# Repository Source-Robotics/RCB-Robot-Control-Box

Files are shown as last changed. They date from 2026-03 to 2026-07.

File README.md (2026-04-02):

> [!CAUTION]
> This is a BETA release: Instructions, code, and 3D print files may change in the future and are not yet finalized.

By building and using this system, you acknowledge that it is still under active development and may contain errors, incomplete features, or design issues. You are doing so entirely at your own risk and responsibility.

This project may require troubleshooting, modifications, and technical knowledge. Proceed only if you are comfortable working with electronics, mechanical systems, and software in a development-stage environment.
>

## 🐞 Beta Feedback

Since this project is currently in beta, feedback is highly appreciated.

If you find any mistakes, bugs, or unclear parts, please report them, including issues in:

- Documentation
- BOM and assembly documentation
- Source code
- STL and other 3D print files

Please open an issue, send us a message on Discord, or contact us via email with as much detail as possible so we can fix it quickly.



<div align="center">

# RCB - ROBOT CONTROL BOX


     
<p align="center">
  
  
  
  
  
  
</p>

</div>

## 📖 Project Overview

RCB - Robot Control Box  is basically the brain + interface hub of the PAR6 robot, it:

* Runs the real-time control algorithms
* Connects to the robot arm (motors, sensors)
* Interfaces with external devices (PCs, PLCs, sensors)
* Handles safety systems
* Provides user interface / programming environment

There is no need for external PC, the Box uses raspberry pi to control your robotic arm.

## ⚒️How to build / Where to buy?

* Assembly manual is TODO.

* Source all the parts yourself from the BOM folder!

* Print files from the STEP files folder.

## 📚Resources:

| Resource | Description |
|---|---|
| [RCB motherboard firmware](RCB%20motherboard%20firmware/) | Firmware source and PlatformIO project for the control box motherboard |
| [BOX STEP 3D print files](STEP%20files/) | STEP files for the control box enclosure and printed parts |
| [BOM](BOM/BOM.md) | Bill of materials and reference images for required components |
| [Assembly manual](Assembly%20manual/readme.md) | Build and assembly instructions for the control box TODO |

## 🌐 More about our projects

| YouTube | Instagram | Twitter | LinkedIn |
|---|---|---|---|
|  |  |  |  |

| Discord | Forum | Hackaday | Blog |
|---|---|---| ---|
|  |  |  |  

## ⚠️ Safety, Liability & Disclaimer
This project includes experimental software, hardware designs, and assembly documentation that are still under development and may contain bugs, errors, or incomplete features. By using, building, or modifying this project, you acknowledge that:

* You use this project entirely at your own risk
* You are solely responsible for safe assembly, testing, and operation
* No guarantee is made regarding correctness, safety, or reliability
* The authors are not responsible for any damage, injury, or loss resulting from the use or misuse of this project
* Hardware performance and safety depend on user assembly, component quality, calibration, and handling, which cannot be guaranteed
* This project is provided “as is.” If you choose to build a device yourself using these files, designs, or instructions, you do so without any warranties or guarantees, including regarding safety, reliability, or suitability for any particular purpose.

THIS PROJECT INVOLVES LETHAL VOLTAGES AND OTHER SERIOUS HAZARDS THAT CAN CAUSE SEVERE INJURY. YOU MUST READ THE FULL [SAFETY WARNING AND DISCLAIMER DOCUMENT](SAFETY_WARNING_AND_DISCLAIMER.md)  BEFORE USING ANY PROJECT FILES. BY PROCEEDING, YOU ACKNOWLEDGE AND ACCEPT ALL RISKS AND AGREE TO USE THIS PROJECT ENTIRELY AT YOUR OWN RESPONSIBILITY.

## 💸Support us

The majority of this project is open source and freely available to everyone. Your assistance, whether through donations or advice, is highly valued. Thank you!

 


## 🛡️ Licensing
 Project is under the [MIT License](LICENSE).

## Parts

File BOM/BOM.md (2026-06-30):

# RCB Robot Control Box – Bill of Materials (BOM)

This BOM lists all components required to build RCB Robot Control Box. Quantities are for **one RCB**.

> [!NOTE]
> If any product links are broken, unavailable, or no longer point to the correct item, please [open an issue](https://github.com/Source-Robotics/RCB-Robot-Control-Box/issues/new), send us a message on Discord, or contact us via email. You can also use the reference images to find the same or an equivalent part from another supplier.

---

## Screws and Nuts

| Diameter / Type | Length | Quantity | Description |
|---|---|---|---|
| M2.5 nut |  | 4 |  |  |
| M3  |  8mm| 12 | DIN 912 / ISO 4762 (Socket head cap) |  
| M3  | 20mm | 2 | DIN 912 / ISO 4762 (Socket head cap) |  
| M3  | 30mm | 1 |  DIN 912 / ISO 4762 (Socket head cap)|  
| M3 tappered head  | 6mm | 11 | Tapered / Countersunk screw head |  
| M2 | 6mm | 2 |  DIN 912 / ISO 4762 (Socket head cap) | 
| M2.5 | 18mm | 4 | Any type |  

---

## Brass Inserts

| Thread | Length | Outer Diameter | Quantity | Link | Reference Image |
|---|---|---|---|---| ---|
| M3 | 5 mm | 4.5 mm | 13 | [Link](https://s.click.aliexpress.com/e/_c2RX6lzp)  |[Link](BOM%20reference%20images/brass_insert.png) |

---

## Mechanical Components

| Type | Quantity | Description | Link | Reference Image |
|---|---|---|---| ---|
| Rubber feet | 4 | See reference image for exact type | [Link](https://s.click.aliexpress.com/e/_c2xnQgI7)  |[Link](BOM%20reference%20images/Rubber_feet.png) |

---
female_female_jumper_wire
## Electronics

| Type | Quantity | Description | Link | Reference Image |
|---|---|---|---| ---|
| RCB Motherboard | 1 |  | Source Robotics website only for beta for now | [Link](BOM%20reference%20images/Motherboard.png) |
| Raspberry pi - Motherboard connector PCB | 1 | Connects pi5 to motherboard | Source Robotics website only for beta for now  | [Link](BOM%20reference%20images/P1066620.jpg) |
| UHP-200-24 MEAN WELL power supply | 1 |  | [Link](https://hr.mouser.com/ProductDetail/709-UHP-200-24) | [Link](BOM%20reference%20images/psu.png) |
| I2C Oled display 128x64 0.96 inch | 1 |  | [Link](https://s.click.aliexpress.com/e/_c3Gz8Xj7) | [Link](BOM%20reference%20images/OLED.png) |
| Power socket | 1 |  | [Link](https://s.click.aliexpress.com/e/_c3jE9sYt) | [Link](BOM%20reference%20images/Power_plug.png) |
| ON/OFF Button | 1 | 12mm 3-6V, NOT LATCHING  | [Link](https://s.click.aliexpress.com/e/_DBpZV3h) | [Link](BOM%20reference%20images/button.png) |
| 3mm LED diode (green recommended) | 2 | Indicator LEDs | [Link](https://s.click.aliexpress.com/e/_c39Q5Qz7) |  [Link](BOM%20reference%20images/green_lred_3mm.webp) |
| 12 AWG wire | 1meter | Wire used for Power socket and Power supply - motherboard connection | Local store | [Link](BOM%20reference%20images/instalation_wire.jpg) |
| 2.54 Female - Female wire 10cm | 4 | Wires used for OLED display | [Link](https://s.click.aliexpress.com/e/_c2xKgSEl) | [Link](BOM%20reference%20images/female_female_jumper_wire.jpg) |
| JST PH 2.0mm 200mm 4PIN | 1 | Cable used for power button | [Link](https://s.click.aliexpress.com/e/_DeObQ1D) | [Link](BOM%20reference%20images/wire.png) |
| Raspberry pi 5 4gb or higher | 1 |  |  | [Link](BOM%20reference%20images/pi5.png) |
| GX16 4PIN connector male | 1 |  | [Link](https://s.click.aliexpress.com/e/_c3o4afqR) | [Link](BOM%20reference%20images/GX16.jpg) |
| SV 1.25-4S Spades/Fork Connector | 7 | Used for Power socket and MEANWELL power supply | [Link](https://s.click.aliexpress.com/e/_c31y7RJF) | [Link](BOM%20reference%20images/Fork_spade_plug.png)  |
| MICRO-FIT 3.0 2Pin | 1 | Cable from GX16 to motherboard  | [Link](https://hr.mouser.com/ProductDetail/Molex/214755-1021?qs=vmHwEFxEFR9098107Evnhw%3D%3D) [Aliexpress link](https://s.click.aliexpress.com/e/_c3MQyASH) | [Link](BOM%20reference%20images/Micro_fit_3_0_2pin.png) |
| JST ZH 1.5MM 2PIN female-female 23cm | 1 | Cable from GX16 to motherboard  | [Link](https://s.click.aliexpress.com/e/_c39pDT7b) | [Link](BOM%20reference%20images/ZH_series_dual_female_head.jpg) |

### Raspberry Pi Cooling Options

Choose **one** cooling option: either use the 4010 cooling fan with heatsinks, or use the pi5 cooling fan kit.

| Option | Type | Quantity | Description | Link | Reference Image |
|---|---|---|---|---| ---|
| A | 4010 - Cooling fan 40x40x10, 5V | 1 | Use together with the heatsinks below. | [Link](https://s.click.aliexpress.com/e/_c3anlQut) | [Link](BOM%20reference%20images/cooling_fan_4010.png) |
| A | Heatsinks | 1 set | Use together with the 4010 cooling fan above. | [Link](https://s.click.aliexpress.com/e/_c4BNGgDT) | [Link](BOM%20reference%20images/heatsink.png) |
| B | pi5 cooling fan kit | 1 | Use this instead of the 4010 cooling fan and heatsinks. | [Link](https://s.click.aliexpress.com/e/_c3OpTQ3J) [alt link](https://s.click.aliexpress.com/e/_c3oBDnrF) | [Link](BOM%20reference%20images/pi5_cooling_kit.png) |

### Optional Cables

| Type | Quantity | Description | Link | Reference Image |
|---|---|---|---| ---|
| MICRO-FIT 3.0 2PIN connector or cable | 1 | Optional spare or alternate cable/connector. | [Link](https://s.click.aliexpress.com/e/_c3MQyASH) | [Link](BOM%20reference%20images/microfit2.png) |
| MICRO-FIT 3.0 8PIN connector or cable | 1 | Optional spare or alternate cable/connector. | [Link](https://s.click.aliexpress.com/e/_c3G9mlNf) | [Link](BOM%20reference%20images/microfit8.png) |

---

## PAR6 Robot cable (Robot base to RCB (Robot Control Box) cable)

* Follow the assembly manual [here](../Assembly%20manual/Building_cables.md)
* Video manual [here](https://youtu.be/QlNfWAga1l0)

| Type | Quantity | Description | Link | Reference Image |
|---|---|---|---| ---|
| GX16 4PIN connector female | 2 |  | [Link](https://s.click.aliexpress.com/e/_c3o4afqR) | [Link](BOM%20reference%20images/GX16.jpg) |
| Twisted Pair Shielded Cable 4 cores - 24AWG or 22AWG | 2m recommended |  | [Link](https://s.click.aliexpress.com/e/_c34NcZIT) | [Link](BOM%20reference%20images/TWISTED.png) |

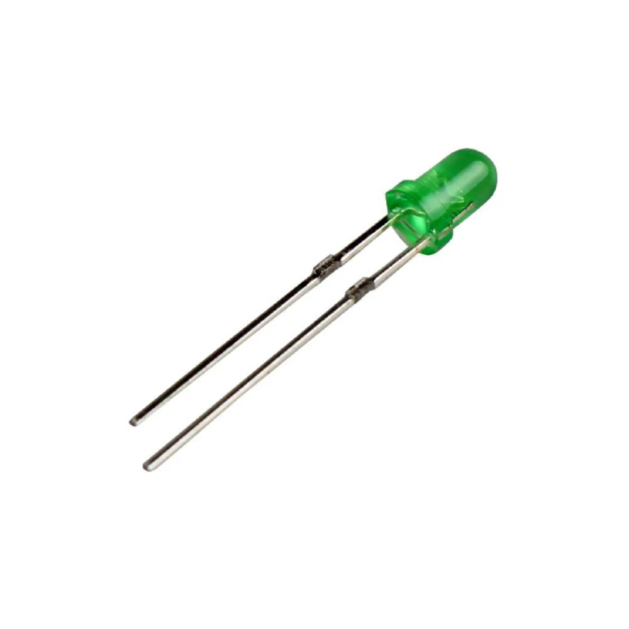
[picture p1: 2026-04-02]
BOM/BOM reference images/green_lred_3mm.webp

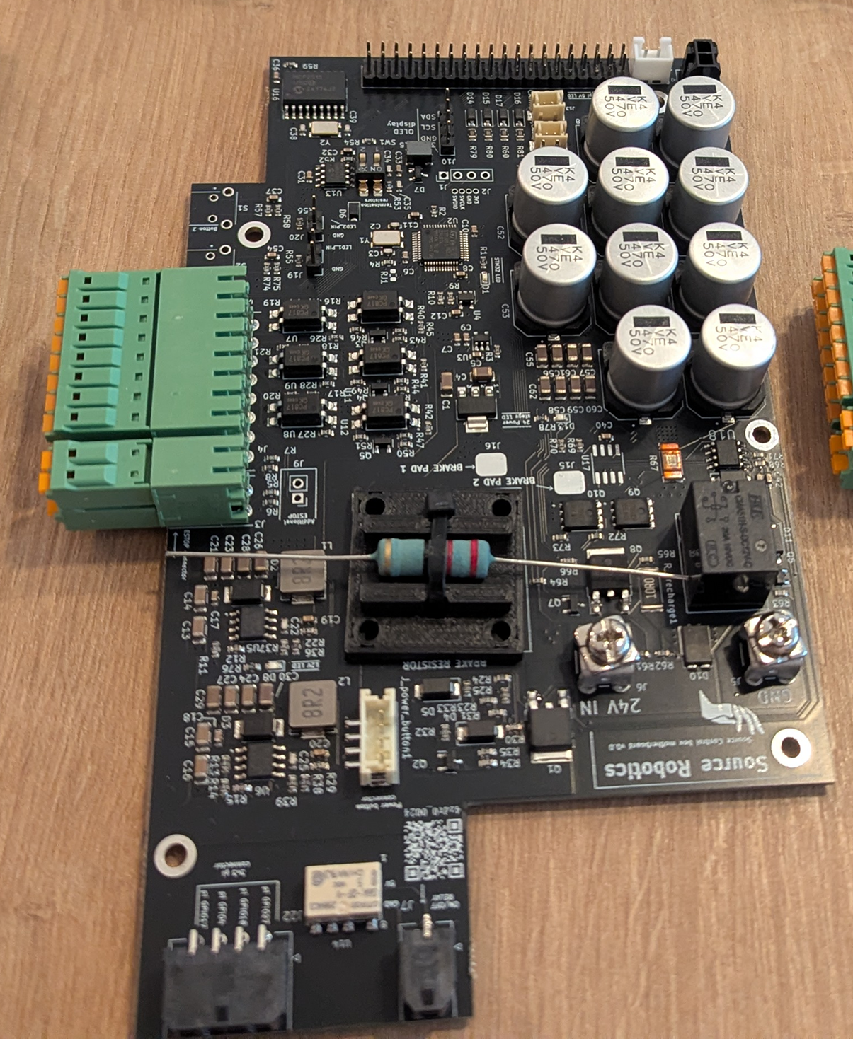
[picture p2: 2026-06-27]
BOM/BOM reference images/Motherboard.png

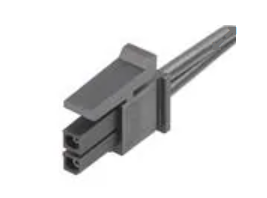
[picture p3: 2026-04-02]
BOM/BOM reference images/Micro_fit_3_0_2pin.png

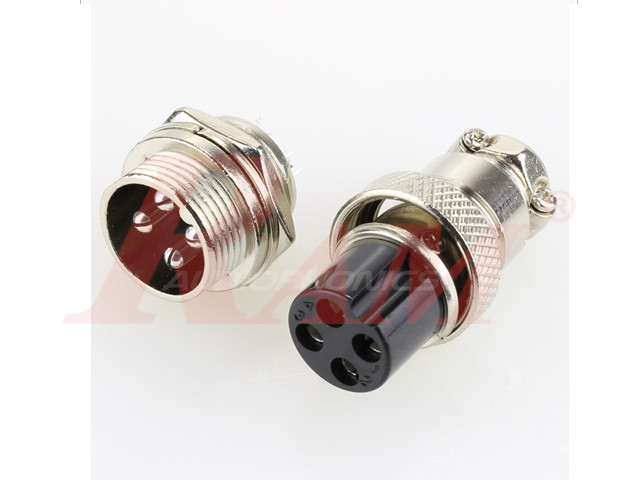
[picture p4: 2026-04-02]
BOM/BOM reference images/GX16.jpg

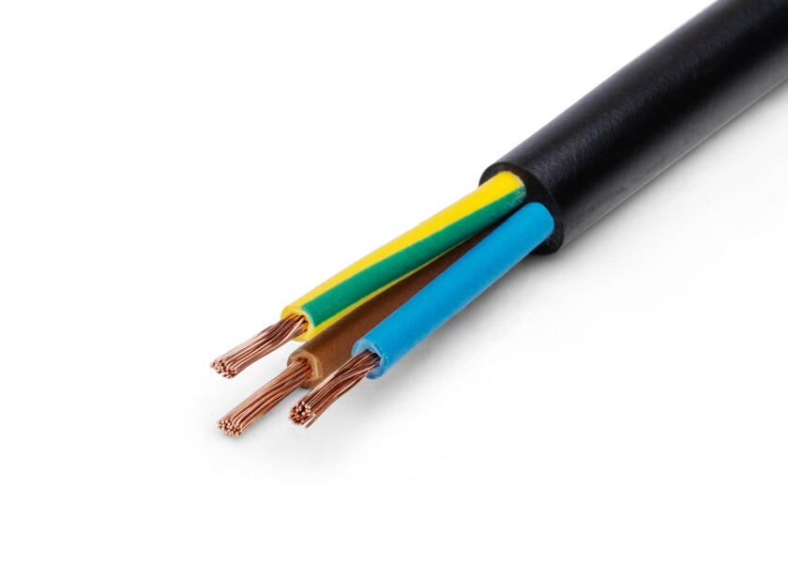
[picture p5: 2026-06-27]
BOM/BOM reference images/instalation_wire.jpg

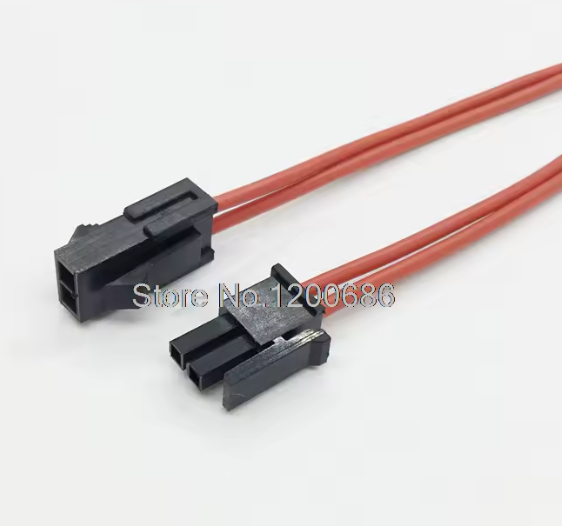
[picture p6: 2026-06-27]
BOM/BOM reference images/microfit2.png

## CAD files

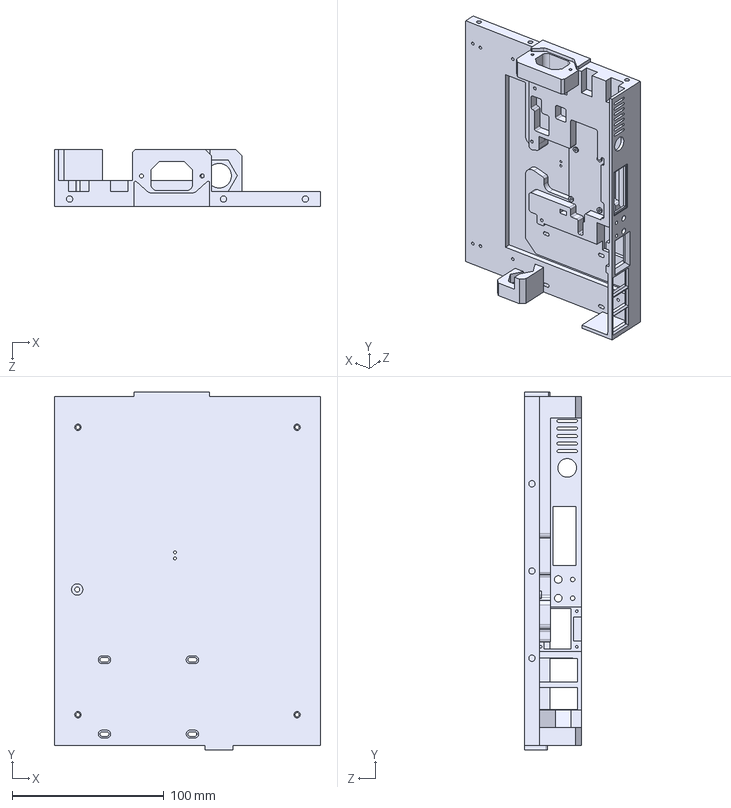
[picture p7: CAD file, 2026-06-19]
STEP files/Control_box_bottom.STEP
175.5 x 236.1 x 37.8 mm

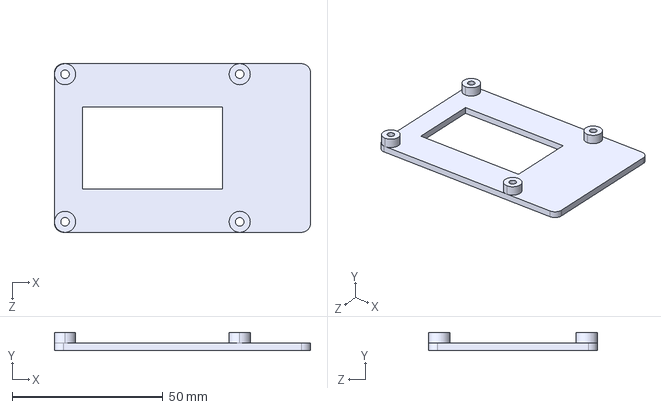
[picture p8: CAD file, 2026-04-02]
STEP files/pi_bottom.STEP
85.0 x 6.10 x 56.0 mm

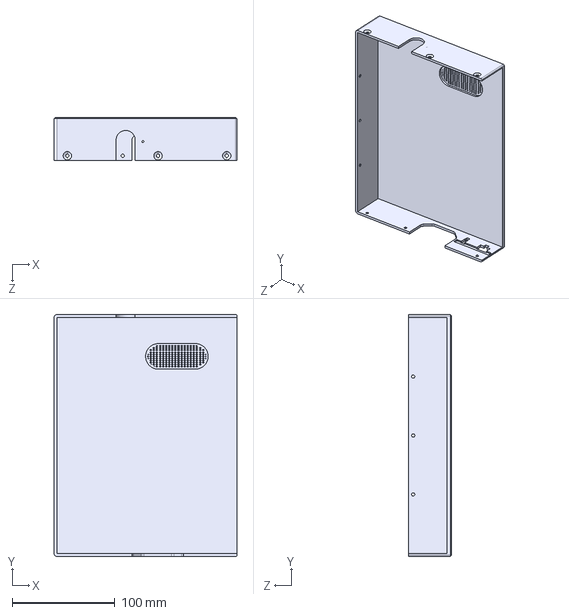
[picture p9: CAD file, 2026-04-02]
STEP files/Control_box_lid_no pattern.STEP
178.5 x 236.1 x 41.8 mm

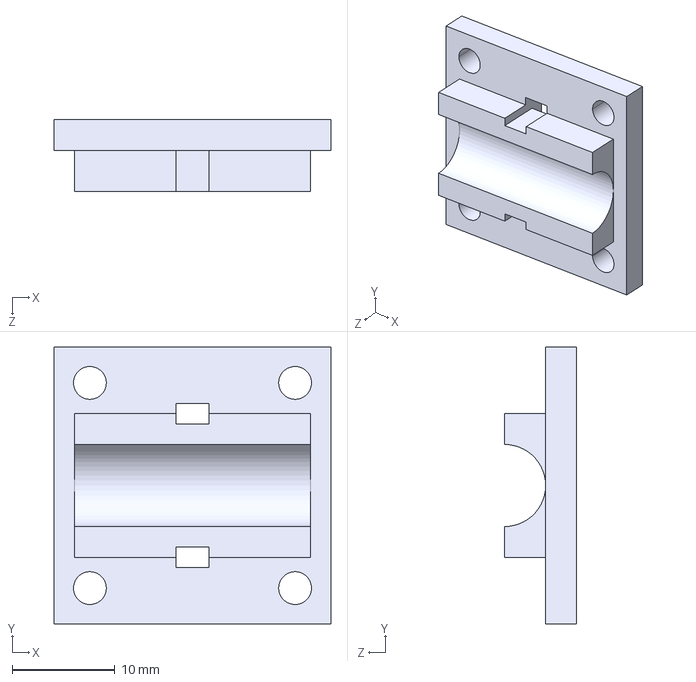
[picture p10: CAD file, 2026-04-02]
STEP files/resistor_holder.STEP
27.0 x 27.0 x 7.00 mm

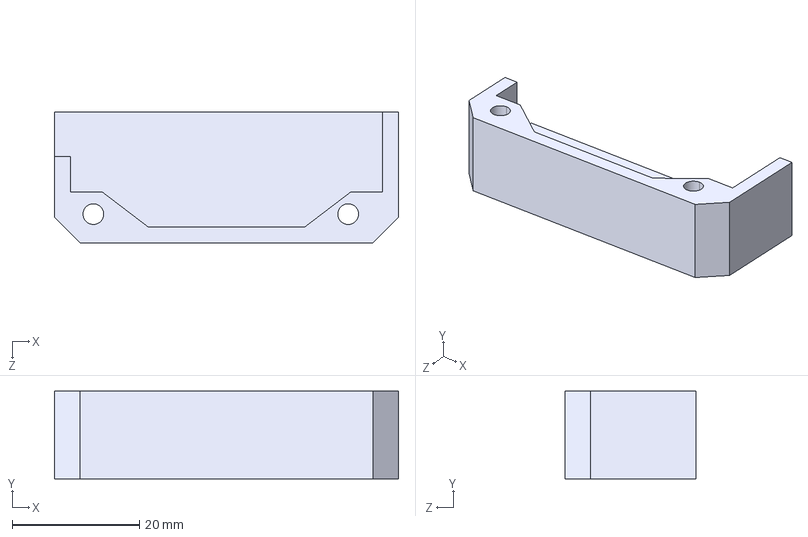
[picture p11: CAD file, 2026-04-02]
STEP files/Socket_cover.STEP
54.0 x 13.8 x 20.6 mm

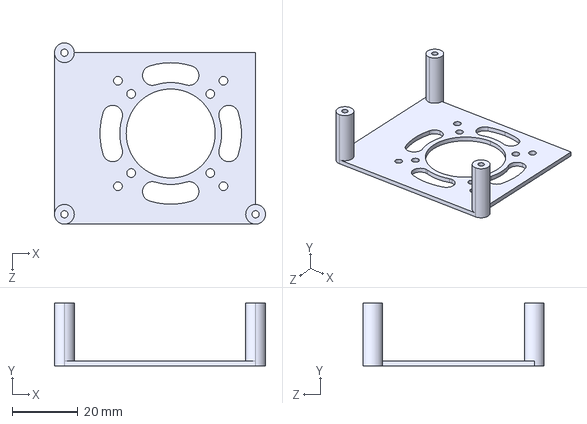
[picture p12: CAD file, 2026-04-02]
STEP files/pi_fan_holder.STEP
64.0 x 19.0 x 55.0 mm

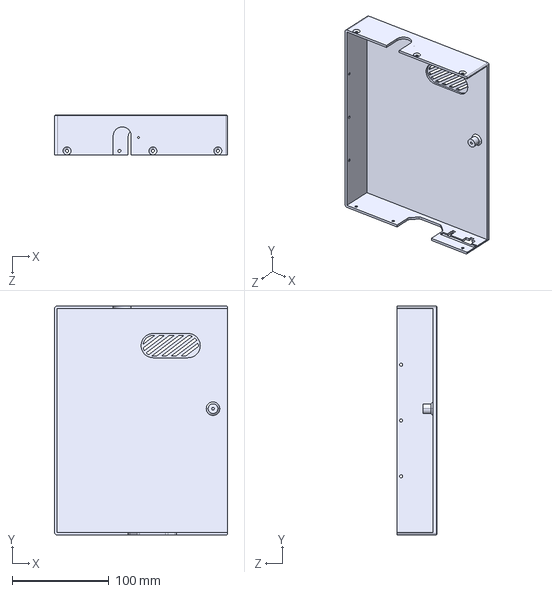
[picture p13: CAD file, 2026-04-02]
STEP files/Control_box_top_ribbed.STEP
178.5 x 236.1 x 41.8 mm

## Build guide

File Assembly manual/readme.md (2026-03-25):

Check youtube video assembly manual: Link

PDF TODO

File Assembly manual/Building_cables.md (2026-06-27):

## PAR6 Robot cable (Robot base to RCB (Robot Control Box) cable)

Parts needed:
* [2 x GX16 4PIN connector female](https://s.click.aliexpress.com/e/_c3o4afqR)
* [Twisted Pair Shielded Cable 4 cores - 24AWG or 22AWG](https://s.click.aliexpress.com/e/_c34NcZIT)

Check the video tutorial [here](https://youtu.be/QlNfWAga1l0)

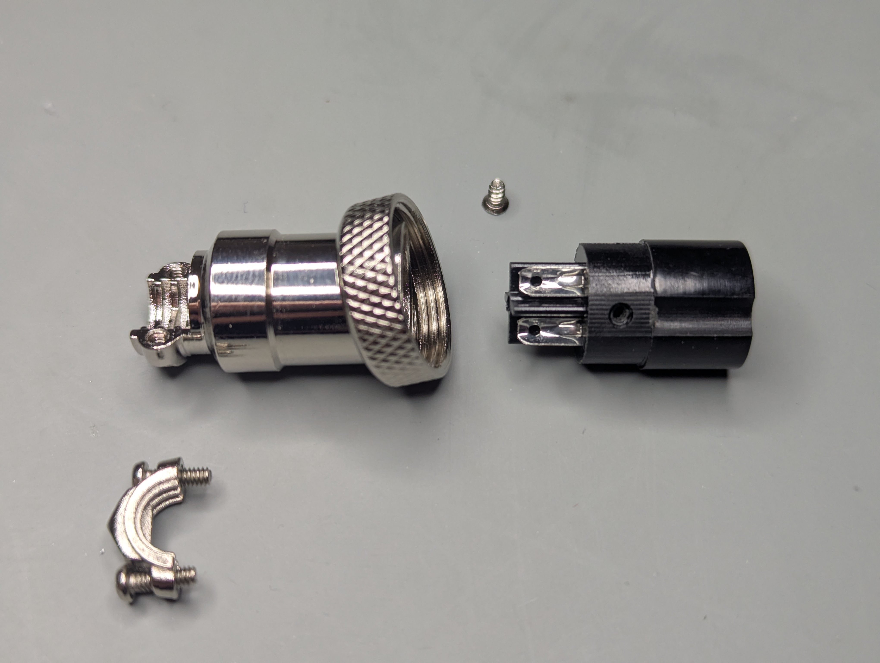
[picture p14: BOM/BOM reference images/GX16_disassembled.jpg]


**Dissasemble the connector.**

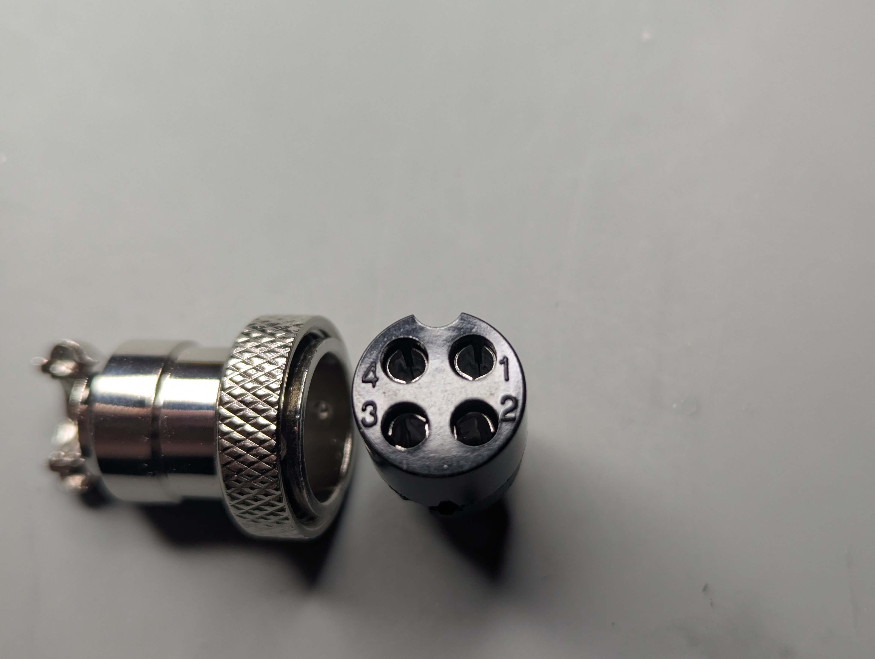
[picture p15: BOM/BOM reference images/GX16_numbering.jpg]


**Connector has numbering on both sides.** 

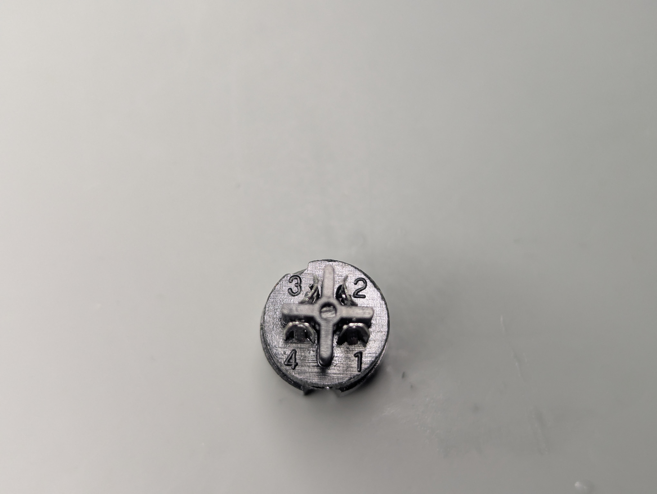
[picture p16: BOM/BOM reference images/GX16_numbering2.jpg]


**When assembling the cable you solder pins 1-1, 2-2, 3-3, 4-4. Do that for the both sides of the cable!** 

> **Note:** Equivalent parts from other suppliers may be used as long as specifications match.

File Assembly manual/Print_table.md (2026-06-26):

## USE 25% Infill for all! We used PETG filament!

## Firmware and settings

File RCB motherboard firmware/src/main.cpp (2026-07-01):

#include "stm32f1xx_hal.h"
#include "iodefs.h"
#include "constants.h"
#include "adc_init.h"
#include "pwm_init.h"
#include "hw_init.h"
#include "qfplib-m3.h"
#include "utils.h"
#include "EEPROM.h"
#include "debounce.h"
#include "SerialPacketParser.h"
#include "communication.h"
#include "common.h"

// Define serial port
#define Serial Serialx
#define TIMING_DEBUG 1
HardwareSerial Serialx(RX_COM, TX_COM); // PA3, PA2 RX,TX

// Define timer for PWM
HardwareTimer *MyTim2;
ADC_HandleTypeDef hadc1;

// Define button debounce and press handler
ButtonHandler button(Button_state);

// Exponential Moving Average (EMA) filter coefficients
#define EMA_A_V1 0.15
#define EMA_A_V2 0.15
#define EMA_A_C 0.15

String command_ = "idle";
String status = "test";

// Button function
void handleButtonActions() {
  switch (button.getState()) {
    case PRESSED:
        Serial.println("Single Press detected");
        break;
    case DOUBLE_PRESS:
        Serial.println("Double Press detected");
        break;
    case TRIPLE_PRESS:
        Serial.println("Triple Press detected");
        break;
    case HELD_2S:
        Serial.println("Button Held for 2 seconds");
        break;
    case HELD_3S:
        Serial.println("Button Held for 3 seconds");
        break;
    default:
        break;
}
button.resetState(); // Reset state after handling
}



void setup () {

  // Init system
  HAL_Init();
  SystemClock_Config();
  TM_SystemClock_Config(CLOCK_PRESCALE); //15, Clock speed = 8*15

  // Init digital inputs and outputs
  Init_Digital_Inputs();
  Init_Digital_Outputs();
  GPIO_init();

  // Init ADC
  MX_ADC1_Init();
  HAL_ADCEx_Calibration_Start(&hadc1);

  // Begin serial
  Serial.begin(SERIAL_SPEED);

  // Begin PWM 50000 = 25Khz -> center aligned
  // PWM duty for 25khz goes from 0 - 5120 if CPU clock is 128 Mhz
  MyTim2 = pwm_high(PRECHARGE_PIN, PWM_FREQ * 2);
  MyTim2 = pwm_high(PWM_BRAKE, PWM_FREQ * 2);
  pwm_align(MyTim2);

  // EEPROM stuff
  digitalWriteFast(EEPROM_WP, LOW);
  Init_EEPROM();
  //Write_config();
  Set_Default_config();
  read_config();

  // Init timer ticker with callback function
  Ticker_init(TIM3, LOOP_FREQ, IT_callback);

  // Disable relay and precharge FET on startup instantly
  digitalWriteFast(RELAY_PIN, HIGH); // relay is OFF
  pwm_set(PRECHARGE_PIN, PWM_MIN, 13); // 0V, Precharge FET is off, current goes thru relay

  // Enable brake FET to discharge capacitors that got slightly charged because of the relay is in NC state on startup
  digitalWriteFast(EN_BRAKE_FET, HIGH); // // Set PC15 HIGH, Enable brake FET   //HAL_GPIO_WritePin(GPIOA, GPIO_PIN_8, GPIO_PIN_SET);  
  pwm_set(PWM_BRAKE, PWM_MAX-10, 13); // 3V3, BRAKE FET  PWM

  // Small delay
  delay(500);

  // DISABLE brake FET
  digitalWriteFast(EN_BRAKE_FET, LOW); // Set PC15 LOW, Disable brake FET  //HAL_GPIO_WritePin(GPIOA, GPIO_PIN_8, GPIO_PIN_RESET);  
  pwm_set(PWM_BRAKE, PWM_MIN + 10, 13); // 0V, BRAKE FET is OFF

  // Enable precharge FET and wait a bit for CAPS to charge
  digitalWriteFast(RELAY_PIN, HIGH); // relay is OFF
  pwm_set(PRECHARGE_PIN, PWM_MAX, 13); // 3V3, Precharge FET is on
  delay(300);

  // Disable precharge FET and turn on relay 
  pwm_set(PRECHARGE_PIN, PWM_MIN, 13); // 0V, Precharge FET is off
  digitalWriteFast(RELAY_PIN, LOW); // relay is ON

  


}

void loop () {

  #if (TIMING_DEBUG > 0)
  int c = micros();
  #endif

  // Global ticker for timing
  uint32_t ms = HAL_GetTick();
  static uint32_t last_time = 0;

  // Turn on raspberry pi
  digitalWriteFast(Pi_enable, HIGH); 


  int vbus1 = Get_voltage_mA(ADC_CHANNEL_5_READ_VBUS1());
  int vbus2 = Get_voltage_mA(ADC_CHANNEL_4_READ_VBUS2());
  int current = Get_current_mA(ADC_CHANNEL_3_READ_CURRENT());


  // Apply integer-based EMA filtering

  controller.filtered_VBUS1_mV = (int)qfp_fadd(qfp_fmul(EMA_A_V1, vbus1), qfp_fmul(qfp_fsub(1, EMA_A_V1), controller.filtered_VBUS1_mV));
  controller.filtered_VBUS2_mV = (int)qfp_fadd(qfp_fmul(EMA_A_V2, vbus2), qfp_fmul(qfp_fsub(1, EMA_A_V2), controller.filtered_VBUS2_mV));
  controller.filtered_Current_mA = (int)qfp_fadd(qfp_fmul(EMA_A_C, current), qfp_fmul(qfp_fsub(1, EMA_A_C), controller.filtered_Current_mA));

  // Brake FET logic
  if (controller.filtered_VBUS2_mV >25000){
    digitalWriteFast(EN_BRAKE_FET, HIGH); // // Set PC15 HIGH, Enable brake FET   //HAL_GPIO_WritePin(GPIOA, GPIO_PIN_8, GPIO_PIN_SET);  
    controller.brake_pwm_duty = 8100;
    pwm_set(PWM_BRAKE, controller.brake_pwm_duty, 13); // 3V3, BRAKE FET  PWM
    digitalWriteFast(LED1, HIGH);
  }

  if(controller.filtered_VBUS2_mV < 25000){
    digitalWriteFast(EN_BRAKE_FET, LOW); // // Set PC15 HIGH, Enable brake FET   //HAL_GPIO_WritePin(GPIOA, GPIO_PIN_8, GPIO_PIN_SET);  
    controller.brake_pwm_duty = 8;
    pwm_set(PWM_BRAKE, controller.brake_pwm_duty , 13); // 3V3, BRAKE FET  PWM
    digitalWriteFast(LED1, LOW);
  }
  ////////////////////////

  if ((ms - last_time) > 500) // run every x ms
  {

    /*
    int vbus1 = ADC_CHANNEL_5_READ_VBUS1();
    int vbus2 = ADC_CHANNEL_4_READ_VBUS2();
    int current = ADC_CHANNEL_3_READ_CURRENT();
    Serial.print("VBUS1: ");
    int vvbus1 = Get_voltage_mA(vbus1);
    int vvbus2 = Get_voltage_mA(vbus2);
    Serial.print(vvbus1);
    Serial.print(" VBUS2: ");
    Serial.print(vvbus2);
    Serial.print(" Current: ");
    Serial.println(Get_current_mA(current));
    Serial.print("exect time: ");
    Serial.println(controller.execution_time);
    */


    // Print filtered integer values


    // TODO Add error state 
    // TODO add power button state
    // Read relay state: 
    int relayState = !digitalRead(RELAY_PIN);
    
    float power_usage = (((controller.filtered_VBUS1_mV + controller.filtered_VBUS2_mV) / 2) * controller.filtered_Current_mA)/1000000;
    Serial.print("$");
    Serial.print(" ");
    Serial.print(controller.filtered_VBUS1_mV);
    Serial.print(" ");
    Serial.print(controller.filtered_VBUS2_mV);
    Serial.print(" ");
    Serial.print(controller.filtered_Current_mA);
    Serial.print(" ");
    Serial.print(power_usage);
    Serial.print(" ");
    Serial.print(relayState);
    Serial.print(" ");
    Serial.print(command_);
    Serial.print(" ");
    Serial.print(status);
    Serial.print(" ");
    Serial.print(controller.SERIAL_NUMBER);
    Serial.print(" ");
    Serial.print(controller.HARDWARE_VERSION);
    Serial.print(" ");
    Serial.print(controller.BATCH_DATE);
    Serial.print(" ");
    Serial.print(controller.SOFTWARE_VERSION);
    Serial.println(" ");

    /*
    Serial.print(controller.filtered_VBUS1_mV );         // first variable is program time in seconds. This can be plotted on an x-axis!
    Serial.print("\t");
    Serial.print(controller.filtered_VBUS2_mV);   // second variable is sin(t)
    Serial.print("\t");      // this last "\t" isn't required, but doesn't hurt
    Serial.println(vbus1); // third varible is cos(t). make sure to finish with a println
    */




    /*
    Serial.print("Terst ");
    Serial.print(Get_voltage_mA(1500));
    Serial.print("Filtered VBUS1: ");
    Serial.print(controller.filtered_VBUS1_mV);
    Serial.print("  Filtered VBUS2: ");
    Serial.print(controller.filtered_VBUS2_mV);
    Serial.print("  Filtered Current: ");
    Serial.println(controller.filtered_Current_mA);
    Serial.print("Exec time: ");
    Serial.println(controller.execution_time);
    */


  last_time = ms;
  }



  /*
  Check for VBUS error
  */
  check_vbus_error(ms);

  /*
  Perform actions based on button state (also debounce it)
  */
  button.update();
  handleButtonActions();

  /*
  UART CLI INTERFACE
  */
  UART_protocol(Serial);
  Cyclic_UART(Serial, ms);

  /*
  Debug variables
  */
  #if (TIMING_DEBUG > 0)
  int c2 = micros();
  controller.execution_time = c2 - c;
  #endif
}

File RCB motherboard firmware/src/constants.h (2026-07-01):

/* USER CODE BEGIN Header */
/**
 ******************************************************************************
 * @file    constants.h
 * @brief   This file provides code where we declare constants
 * @author Petar Crnjak
 ******************************************************************************
 * @attention
 *
 * Copyright (c) Source robotics.
 * All rights reserved.
 *
 * This software is licensed under terms that can be found in the LICENSE file
 * in the root directory of this software component.
 * If no LICENSE file comes with this software, it is provided AS-IS.
 *
 ******************************************************************************
 */

/* Define to prevent recursive inclusion -------------------------------------*/
#ifndef CONSTANTS_H
#define CONSTANTS_H

#define VBUS_ERROR_TIME 4000 // Time in ms for VBUS error detection
#define MAX_DUTY 0.95f

#define MIN_DUTY 0.05f

#define ADC_RESOLUTION_ 12

#define PI 3.14159265359f

#define PI2 6.283185307f

#define PWM_FREQ 25000

#define LOOP_FREQ 5000 

#define LOOP_TIME 0.0002 

#define CLOCK_PRESCALE 14

#define SERIAL_SPEED 256000 // 256000 works, Tested with 1Mbit and works

#define SENSE_RESISTOR 0.0005f

#define ADC_MIDPOINT 1.65f

#define ADC_MIDPOINT_BIT 2048

#define CURRENT_AMP_GAIN 200

#define R1_1 180000

#define R2_1 10000

#define R1_2 180000

#define R2_2 10000

#define PWM_MAX 8191

#define PWM_MIN 0

/*
EEPROM CONSTANTS
*/

///// EEPROM variable address list
#define SERIAL_NUMBER_EEPROM 32
#define HARDWARE_VERSION_EEPROM 36
#define BATCH_DATA_EEPROM 40
#define SOFTWARE_VERSION_EEPROM 48

#endif

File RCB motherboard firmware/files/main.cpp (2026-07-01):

#include "hw_init.h"
#include "pwm_init.h"
#include "utils.h"
#include "stm32f1xx_hal.h"
#include "adc_init.h"
#include "iodefs.h"
#include "qfplib-m3.h"
#include "SerialPacketParser.h"
#include "constants.h"
#include "motor_control.h"
#include <SPI.h>
#include "common.h"
#include "foc.h"
#include "temperature_table.h"
#include "CAN.h"
#include <Wire.h>
#include <I2C_eeprom.h>
#include "communication.h"
#include "EEPROM.h"
#include "communication_CAN.h"





// Define serial port
#define Serial Serialx
HardwareSerial Serialx(RX_COM, TX_COM); // PA3, PA2 RX,TX

// Define timer for PWM
HardwareTimer *MyTim2;
ADC_HandleTypeDef hadc1;

void setup()
{

  SPI.setMOSI(MOSI);
  SPI.setMISO(MISO);
  SPI.setSCLK(CLK);
  SPI.setClockDivider(SPI_CLOCK_DIV8); // High speed (128 / 8 = 16 MHz SPI_1 speed)

  Init_Digital_Inputs();
  Init_Digital_Outputs();

  // Sleep mode input.Logic high to enable device;
  // logic low to enter low-power sleep mode; internal pulldown
  digitalWriteFast(SLEEP, HIGH);
  // Reset input. Active-low reset input initializes internal logic, clears faults,
  // and disables the outputs, internal pulldown
  digitalWriteFast(RESET, HIGH);

  digitalWriteFast(EN1, HIGH);
  digitalWriteFast(EN2, HIGH);
  digitalWriteFast(EN3, HIGH);
  digitalWriteFast(LED, HIGH);

  // Init system
  HAL_Init();
  SystemClock_Config();
  TM_SystemClock_Config(14); //15, Clock speed = 8*15

  // Init ADC
  MX_ADC1_Init();
  HAL_ADCEx_Calibration_Start(&hadc1);

  // Begin serial
  Serial.begin(SERIAL_SPEED);

  delay(50);

  digitalWrite(EEPROM_WP, LOW);
  Init_EEPROM();
  //Write_config();
  read_config();
  delay(100);

  // Begin PWM 50000 = 25Khz -> center aligned
  // PWM duty for 25khz goes from 0 - 5120 if CPU clock is 128 Mhz
  MyTim2 = pwm_high(PWM_CH1, PWM_FREQ * 2);
  MyTim2 = pwm_high(PWM_CH2, PWM_FREQ * 2);
  MyTim2 = pwm_high(PWM_CH3, PWM_FREQ * 2);
  pwm_align(MyTim2);

  // Get initial encoder value!
  Get_first_encoder();

  // Collect data before entering the ISR
  // This fixes velocity error
  
  for (int i = 0; i < 20; i++)
  {
    Collect_data();
    delayMicroseconds(20);
  }

  Ticker_init(TIM3, LOOP_FREQ, IT_callback);

  Setup_CAN_bus();
}

//////////////////////////////////////////////////////////////////////////////

void loop()
{

  uint32_t ms = HAL_GetTick();
  /*
    HANDLE LED
  */
  if (controller.LED_ON_OFF == 1)
  {

    LED_status(ms);
  }

  static uint32_t last_time = 0;

  if ((ms - last_time) > 500) // run every x ms
  {

    //Serial.print("RPM");
    //Serial.println((controller.Velocity_Filter * 60) / 16384);
    //int rpm_speed = (controller.Velocity_Filter * 60) / 16384;
    //float load_correction = PID.Iq_setpoint / (PID.Iq_setpoint - FOC.Iq);
    //float KV_value = (rpm_speed / (controller.VBUS_mV / 1000)) * load_correction;
    //Serial.print("Kv is: ");
    //Serial.println(controller.temp1);
    //Serial.print("Kv loop is: ");
    //Serial.println(KV_value);
    last_time = ms;
  }

  /*
   HANDLE CALIBRATION REPORT
  */
  Calib_report(Serial);
  /*
   UART CLI INTERFACE
  */
  UART_protocol(Serial);
  Cyclic_UART(Serial, ms);
  /*
  HANDLE CAN BUS
  */
  CAN_protocol(Serial);
  CAN_heartbeat(ms);
  CAN_watchdog(ms);



}

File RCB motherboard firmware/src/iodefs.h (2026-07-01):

/* USER CODE BEGIN Header */
/**
  ******************************************************************************
  * @file    iodefs.h
  * @brief   This file provides code for pin declarations
  * @author Petar Crnjak
  ******************************************************************************
  * @attention
  *
  * Copyright (c) Source robotics.
  * All rights reserved.
  *
  * This software is licensed under terms that can be found in the LICENSE file
  * in the root directory of this software component.
  * If no LICENSE file comes with this software, it is provided AS-IS.
  *
  ******************************************************************************
  */

/* Define to prevent recursive inclusion -------------------------------------*/
#ifndef IODEFS_H
#define IODEFS_H

#include <Arduino.h>
#include <stdio.h>

#define PRECHARGE_PIN PA_2 //Driver PRECHARGE PIN
#define PWM_BRAKE PA_1 //Driver PWM BRAKE

#define EN_BRAKE_FET PA_8 // Enable brake fet

#define ESTOP_SIGNAL2 PA_9
#define ESTOP_SIGNAL PA_10
#define ESTOP_MCU_onboard PA_11

#define Pi_enable PC_15

#define RELAY_PIN PB_2

#define LED1 PB_13

#define Supply_on_off PB_14

#define Button_state PB_15

#define EEPROM_SCL PB_10
#define EEPROM_SDA PB_11
#define EEPROM_WP PB_12

#define VBUS2 PA_4 // CHANNEL 4 VBUS_MES2
#define CURRENT_SENSE  PA_3 // CHANNEL 3 CURRENT_SENSE
#define VBUS1 PA_5 // CHANNEL 5  VBUS_MES1

#define TX_COM PB_6
#define RX_COM PB_7


#endif

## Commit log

2026-03-25 initial update
    [Magnet_spacer.STEP, Magnet_spacer_2.STEP, Magnet_stepper_tool.STEP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]
2026-04-02 Update docs
    [Control_box_bottom.STEP, Control_box_lid_no pattern.STEP, Control_box_top_ribbed.STEP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]
2026-06-26 BOM update
2026-06-27 Update BOM
2026-11-05 Assembly readme with its links, the firmware README names the RCB, no empty todo files
    The assembly readme said "Link" without a link and "PDF TODO"; the firmware README still called it the
    parol6 V2 control box; Photos/ and Binaries/ held empty todo.md files (Binaries keeps a short README).
2026-11-05 BOM: BOM.md becomes BOM/README.md, so GitHub shows the BOM when the folder opens
2026-11-05 BOM: a short BOM.md that points to README.md, for the older links; links to the folder

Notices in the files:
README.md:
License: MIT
